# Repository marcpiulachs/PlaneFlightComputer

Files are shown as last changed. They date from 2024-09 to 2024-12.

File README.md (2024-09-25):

# Flight Computer

This project is a flight computer powered by an ESP32-C3 microcontroller, designed to control two motors and two servos. It integrates multiple sensors and supports a range of functionalities that make it suitable for small UAVs and drones. The system is designed to operate on a 300mAh LiPo battery, with built-in charging through USB-C.

## Features

- **ESP32-C3** microcontroller for reliable performance and wireless connectivity.
- **Motor Control:**
  - Motor 1: GPIO4
  - Motor 2: GPIO5
- **Servo Control:**
  - Servo 1: GPIO1
  - Servo 2: GPIO6
- **Sensors:**
  - **MAX17048G** (Fuel Gauge) on Address: `0x36` (00110110b)
  - **BMP388** (Barometric Pressure) on Address: `0x76` (1001100b)
  - **QMC5883L** (Magnetometer) on Address: `0x0d` (0001101b)
  - **ICM-42670-P** (6-axis IMU) on Address: `0x68` (1101000b)
- **LEDs:**
  - Internal LED: GPIO7
  - External LED: GPIO0
- **Battery:**
  - Recommended battery: **300mAh LiPo** for optimal performance
  - **USB-C charging** support for ease of use

## Recommended Hardware

- **Battery:** 300mAh LiPo
- **USB-C charger** (included)

## Pinout

| Component | GPIO Pin  | Description |
|---|---|---|
| Motor 1 | GPIO4 | Motor driver pin |
| Motor 2 | GPIO5 | Motor driver pin |
| Servo 1 | GPIO1 | Servo control pin |
| Servo 2 | GPIO6 | Servo control pin |
| Internal LED | GPIO7 | Status indicator |
| External LED | GPIO0 | Additional LED indicator |
| MAX17048G | I2C (0x36)| Fuel gauge sensor |
| BMP388 | I2C (0x76)| Barometric pressure sensor |
| QMC5883L | I2C (0x0d)| Magnetometer sensor |
| ICM-42670-P | I2C (0x68)| 6-axis IMU sensor |

## Power Management

The flight computer operates on a **300mAh LiPo battery**, which provides sufficient power for typical operations. For convenience, the board features **USB-C charging**, allowing you to charge the battery easily.

## Getting Started

To get started with the flight computer:

1. Connect the appropriate motors, servos, and sensors as listed in the pinout table.
2. Power the device using a 300mAh LiPo battery.
3. Use the onboard USB-C port to charge the battery when needed.

## License

This project is open source and available under the [MIT License](LICENSE).

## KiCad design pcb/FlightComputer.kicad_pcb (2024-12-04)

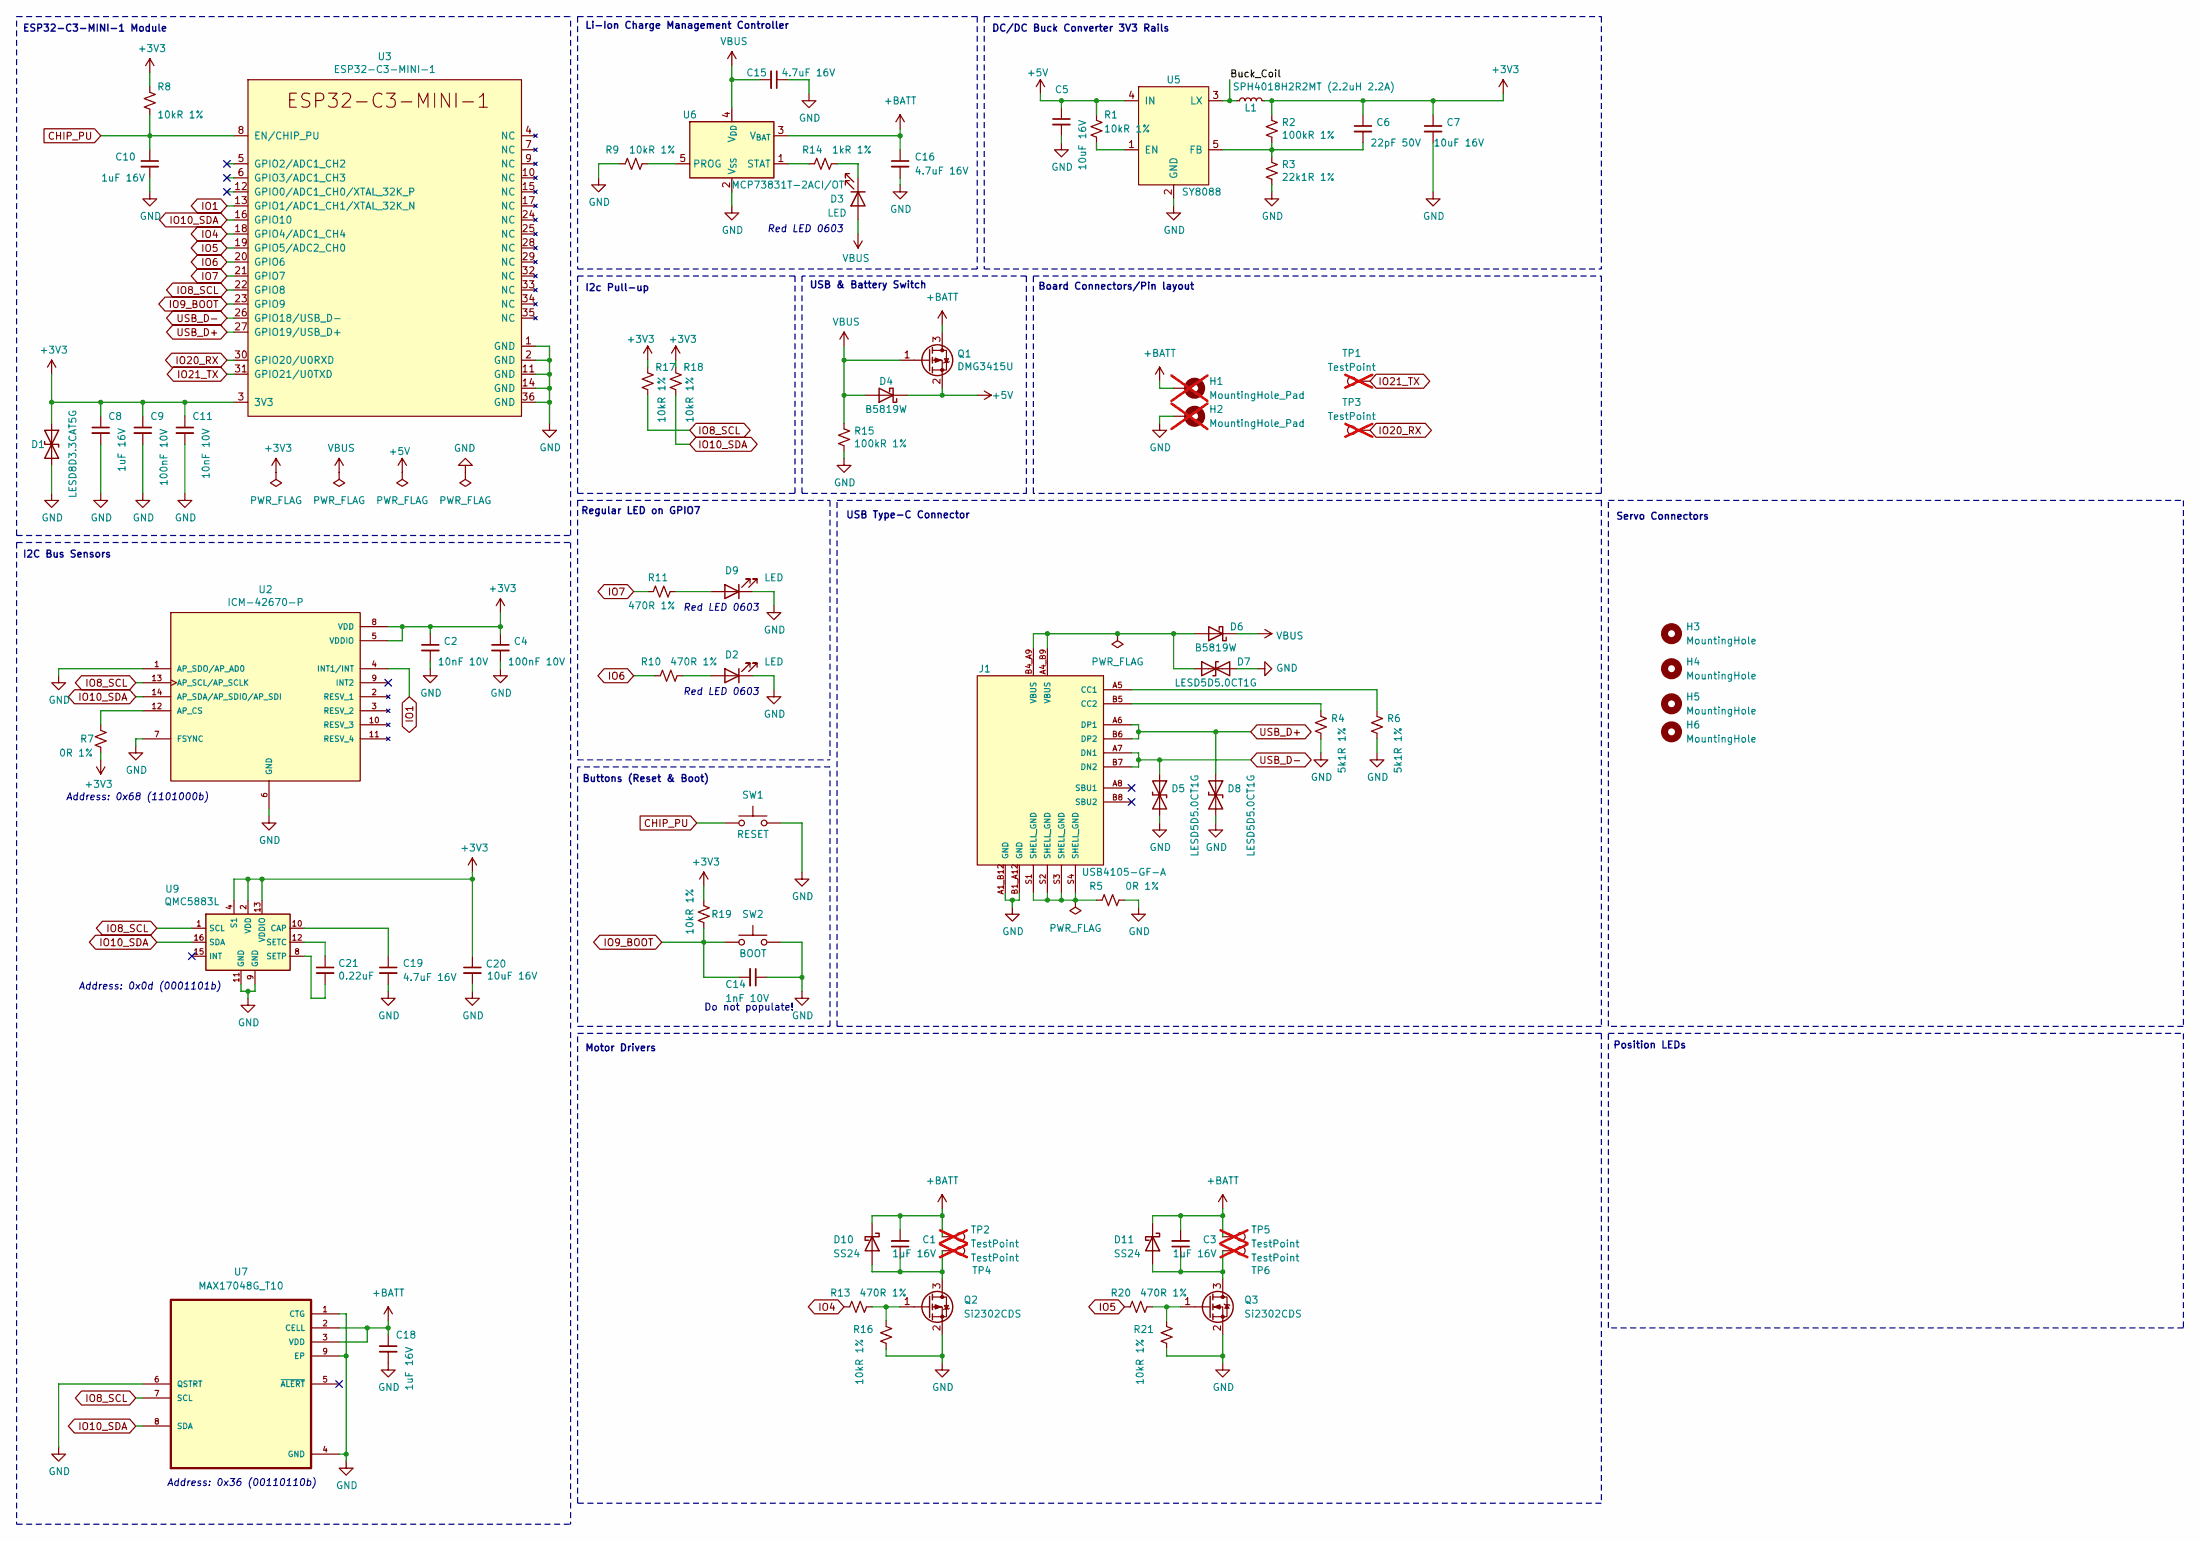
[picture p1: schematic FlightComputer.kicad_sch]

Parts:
C1, C3, C8, C10, C18: 1uF 16V; C_0402_1005Metric; LCSC C52923
C2, C11: 10nF 10V; C_0402_1005Metric; LCSC C15195
C4, C9: 100nF 10V; C_0402_1005Metric; LCSC C1525
C5, C7, C20: 10uF 16V; C_0805_2012Metric; LCSC C15850
C6: 22pF 50V; C_0603_1608Metric; LCSC C1653
C14: 1nF 10V; C_0402_1005Metric; LCSC C1523
C15, C16, C19: 4.7uF 16V; C_0603_1608Metric; LCSC C19666
C21: 0.22uF; C_0402_1005Metric; LCSC C16772
D1: LESD8D3.3CAT5G; D_SOD-882; LCSC C172409
D2, D3, D9: LED; LED_0603_1608Metric; LCSC C2286
D4, D6: B5819W; D_SOD-123; LCSC C8598
D5, D7, D8: LESD5D5.0CT1G; D_SOD-523; LCSC C383211
D10, D11: SS24; D_SOD-123; LCSC C5380709
H1, H2: MountingHole_Pad; TestPoint_Pad_D2.0mm; not fitted
H3, H4, H5, H6: MountingHole; MountingHole_2.2mm_M2_DIN965
J1: USB4105-GF-A; GCT_USB4105-GF-A; PARTREV A3; LCSC C165948
L1: SPH4018H2R2MT (2.2uH 2.2A); L_Bourns-SRN4018; LCSC C370436
Q1: DMG3415U; SOT-23; LCSC C96616
Q2, Q3: Si2302CDS; SOT-23; LCSC C10488
R1, R8, R9, R16, R17, R18, R19, R21: 10kR 1%; R_0402_1005Metric; LCSC C25744
R2, R15: 100kR 1%; R_0402_1005Metric; LCSC C25741
R3: 22k1R 1%; R_0402_1005Metric; LCSC C43473
R4, R6: 5k1R 1%; R_0402_1005Metric; LCSC C25905
R5, R7: 0R 1%; R_0402_1005Metric; LCSC C17168
R10, R11, R13, R20: 470R 1%; R_0402_1005Metric; LCSC C25117
R14: 1kR 1%; R_0402_1005Metric; LCSC C11702
SW1: RESET; SW_SPST_PTS810; LCSC C116501
SW2: BOOT; SW_SPST_PTS810; LCSC C116501
TP1, TP3: TestPoint; TestPoint_Pad_D1.0mm; not fitted
TP2, TP4, TP5, TP6: TestPoint; TestPoint_Pad_D2.0mm; not fitted
U2: ICM-42670-P; LGA-14_3x2.5mm_P0.5mm_LayoutBorder3x4y; PARTREV 1.0; LCSC C3288646
U3: ESP32-C3-MINI-1; LCSC C2838502
U5: SY8088; SOT-23-5; LCSC C479072
U6: MCP73831T-2ACI/OT; SOT-23-5; LCSC C424093
U7: MAX17048G_T10; TDFN-8-1EP_2x2mm_P0.5mm_EP0.8x1.2mm; LCSC C2682616
U9: QMC5883L; LGA-16_3x3mm_P0.5mm; LCSC C976032

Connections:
+3V3: C2.1, C4.1, C6.1, C7.1, C8.1, C9.1, C11.1, C20.1, D1.1 (A1), L1.2, R2.1, R7.2, R8.1, R17.1, R18.1, R19.1, U2.5 (VDDIO), U2.8 (VDD), U3.3 (3V3), U9.2 (VDD), U9.4 (S1), U9.13 (VDDIO)
+5V: C5.1, D4.1 (K), Q1.2 (S), R1.1, U5.4 (IN)
+BATT: C1.2, C3.2, C16.1, C18.1, D10.1 (K), D11.1 (K), H1.1, Q1.3 (D), TP2.1, TP5.1, U6.3 (V_{BAT}), U7.2 (CELL), U7.3 (VDD)
/Buck_Coil: L1.1, U5.3 (LX)
CHIP_PU: C10.1, R8.2, SW1.1, U3.8 (EN/CHIP_PU)
GND: C2.2, C4.2, C5.2, C7.2, C8.2, C9.2, C10.2, C11.2, C14.1, C15.1, C16.2, C18.2, C19.2, C20.2, D1.2 (A2), D2.1 (K), D5.2 (A2), D7.2 (A2), D8.2 (A2), D9.1 (K), H2.1, J1.A1_B12 (GND), J1.B1_A12 (GND), Q2.2 (S), Q3.2 (S), R3.2, R4.2, R5.2, R6.2, R9.1, R15.2, R16.2, R21.2, SW1.2, SW2.2, U2.1 (AP_SDO/AP_AD0), U2.6 (GND), U2.7 (FSYNC), U3.1 (GND), U3.2 (GND), U3.11 (GND), U3.14 (GND), U3.36 (GND), U5.2 (GND), U6.2 (V_{SS}), U7.1 (CTG), U7.4 (GND), U7.6 (QSTRT), U7.9 (EP), U9.9 (GND), U9.11 (GND)
IO4: R13.1, U3.18 (GPIO4/ADC1_CH4)
IO5: R20.1, U3.19 (GPIO5/ADC2_CH0)
IO6: R10.1, U3.20 (GPIO6)
IO7: R11.1, U3.21 (GPIO7)
IO8_SCL: R17.2, U2.13 (AP_SCL/AP_SCLK), U3.22 (GPIO8), U7.7 (SCL), U9.1 (SCL)
IO9_BOOT: C14.2, R19.2, SW2.1, U3.23 (GPIO9)
IO10_SDA: R18.2, U2.14 (AP_SDA/AP_SDIO/AP_SDI), U3.16 (GPIO10), U7.8 (SDA), U9.16 (SDA)
IO13: U2.4 (INT1/INT), U3.13 (GPIO1/ADC1_CH1/XTAL_32K_N)
IO20_RX: TP3.1, U3.30 (GPIO20/U0RXD)
IO21_TX: TP1.1, U3.31 (GPIO21/U0TXD)
unnamed: D2.2 (A), R10.2
unnamed: D3.1 (K), R14.2
unnamed: D6.2 (A), D7.1 (A1), J1.A4_B9 (VBUS), J1.B4_A9 (VBUS)
unnamed: D9.2 (A), R11.2
unnamed: C1.1, D10.2 (A), Q2.3 (D), TP4.1
unnamed: C3.1, D11.2 (A), Q3.3 (D), TP6.1
unnamed: J1.A5 (CC1), R6.1
unnamed: J1.B5 (CC2), R4.1
unnamed: J1.S1 (SHELL_GND), J1.S2 (SHELL_GND), J1.S3 (SHELL_GND), J1.S4 (SHELL_GND), R5.1
unnamed: Q2.1 (G), R13.2, R16.1
unnamed: Q3.1 (G), R20.2, R21.1
unnamed: R7.1, U2.12 (AP_CS)
unnamed: R1.2, U5.1 (EN)
unnamed: C6.2, R2.2, R3.1, U5.5 (FB)
unnamed: R9.2, U6.5 (PROG)
unnamed: R14.1, U6.1 (STAT)
unnamed: C19.1, U9.10 (CAP)
unnamed: C21.1, U9.12 (SETC)
unnamed: C21.2, U9.8 (SETP)
USB_D+: D8.1 (A1), J1.A6 (DP1), J1.B6 (DP2), U3.27 (GPIO19/USB_D+)
USB_D-: D5.1 (A1), J1.A7 (DN1), J1.B7 (DN2), U3.26 (GPIO18/USB_D-)
VBUS: C15.2, D3.2 (A), D4.2 (A), D6.1 (K), Q1.1 (G), R15.1, U6.4 (V_{DD})

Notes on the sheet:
USB Type-C Connector
Do not populate!
Buttons (Reset & Boot)
Servo Connectors
Red LED 0603
Motor Drivers
I2c Pull-up
DC/DC Buck Converter 3V3 Rails
USB & Battery Switch
Board Connectors/Pin layout
Address: 0x36 (00110110b)
Address: 0x0d (0001101b)
Regular LED on GPIO7
Position LEDs
Address: 0x68 (1101000b)
ESP32-C3-MINI-1 Module
Li-Ion Charge Management Controller
I2C Bus Sensors

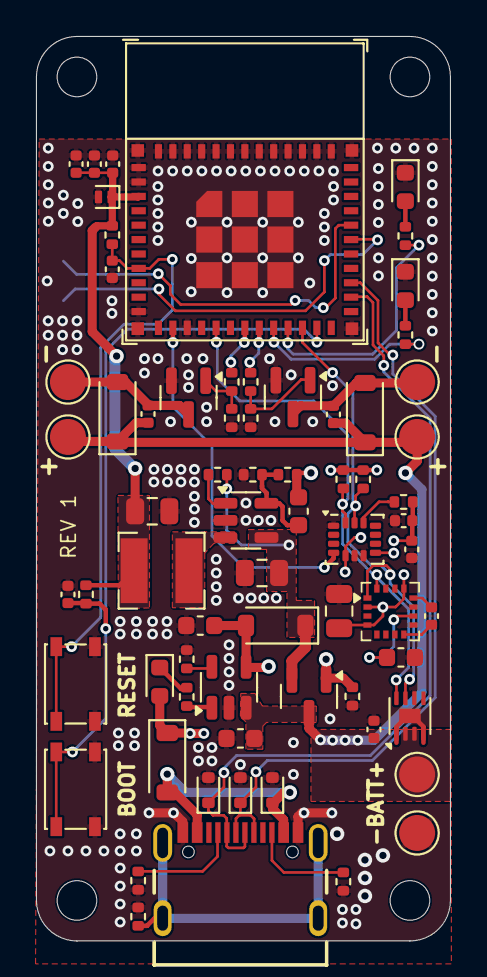
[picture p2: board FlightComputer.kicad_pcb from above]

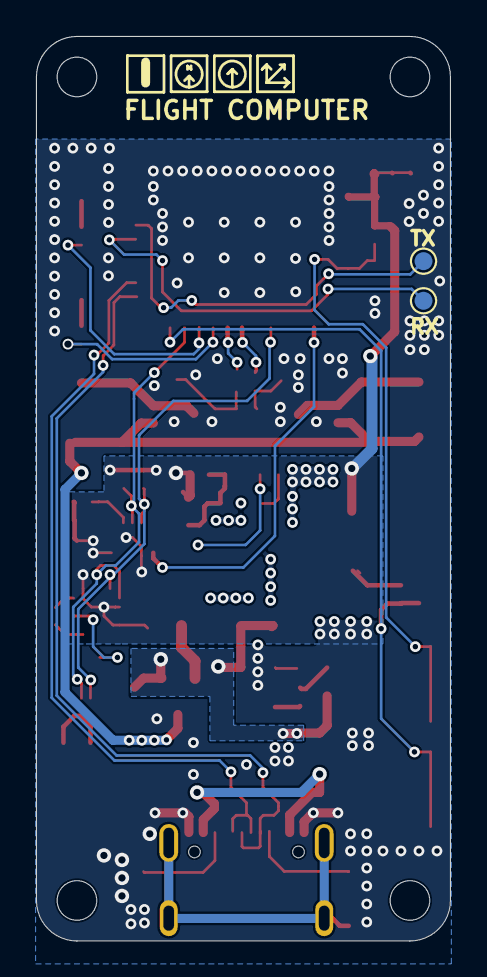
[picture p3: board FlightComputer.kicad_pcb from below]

Board: 2 copper layers, 23.0 x 50.2 mm, 74 parts (2 on the bottom side), 38 nets.

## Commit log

2024-09-06 Remove production files
    [esp-rust-board-B_Cu.gbr, esp-rust-board-B_Mask.gbr, esp-rust-board-B_Paste.gbr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]
2024-09-06 Port kicad 8.0
    [esp-rust-board.kicad_pcb, esp-rust-board.kicad_sch]
2024-09-06 Clean up, update symbols and footprints, port to Kicad 8.0
    [esp-rust-board.kicad_pcb, esp-rust-board.kicad_sch]
2024-09-06 Solve remaining errors and warnings
    [esp-rust-board.kicad_pcb, esp-rust-board.kicad_sch]
2024-09-06 Update package
    [esp-rust-board.kicad_pcb, esp-rust-board.kicad_sch]
2024-09-06 Clean up not used footprints
    [esp-rust-board.kicad_pcb]
2024-09-06 Add new components
    [esp-rust-board.kicad_pcb, esp-rust-board.kicad_sch]
2024-09-10 Work in progress
    [esp-rust-board.kicad_pcb, esp-rust-board.kicad_sch]
2024-09-14 Add magnamometer and barometer and rearrange items
    [esp-rust-board.kicad_pcb, esp-rust-board.kicad_sch]
2024-09-18 Reorganize PCB, remove piezo, temperature sensor and expansion connections
    [esp-rust-board.kicad_pcb, esp-rust-board.kicad_sch]
2024-09-19 Add missing components
    [esp-rust-board.kicad_pcb, esp-rust-board.kicad_sch]
2024-09-19 Place components on PCB
    [esp-rust-board.kicad_pcb, esp-rust-board.kicad_sch]
2024-09-19 Add missing LCSC parts
    [esp-rust-board.kicad_sch]
2024-09-19 Minor corrections
    [esp-rust-board.kicad_pcb]
2024-09-20 Design completed
    [esp-rust-board.kicad_pcb, esp-rust-board.kicad_sch]
2024-09-20 Remove unused rust board
    [esp-rust-board.kicad_pcb, esp-rust-board.kicad_sch]
2024-09-20 Rename Kicad project, rearrange folder structure
    [FlightComputer.kicad_pcb, FlightComputer.kicad_sch]
2024-09-20 Rearrange some vias, minor changes
    [FlightComputer.kicad_pcb, FlightComputer.kicad_sch]
2024-09-25 BMP280 > BMP388
    [FlightComputer.kicad_pcb, FlightComputer.kicad_sch]
2024-09-25 add a few vias, move traces
    [FlightComputer.kicad_pcb]
2024-09-25 Change BMP388 pin to input to reduce warnings
2024-09-25 Correct switch symbol to reduce warnings
    [FlightComputer.kicad_pcb, FlightComputer.kicad_sch]
2024-09-27 Move resistors
    [FlightComputer.kicad_pcb]
2024-09-27 Rotate servos pinouts
    [FlightComputer.kicad_pcb, FlightComputer.kicad_sch]
2024-11-28 Remove barometer
    [FlightComputer.kicad_pcb, FlightComputer.kicad_sch]
2024-12-03 Reduce board size
    [FlightComputer.kicad_pcb, FlightComputer.kicad_sch]
2024-12-03 change Si2319CDS to Si2302CDS
    [FlightComputer.kicad_pcb, FlightComputer.kicad_sch]
2024-12-03 Move battery pads to front
    [FlightComputer.kicad_pcb]
2024-12-03 Change label sizes
    [FlightComputer.kicad_pcb]
2024-12-03 Connect IO0 to IMU interrupt
    [FlightComputer.kicad_pcb, FlightComputer.kicad_sch]
2024-12-04 Hide labels
    [FlightComputer.kicad_pcb]
2024-12-04 Add GND vias, clean up schematic
    [FlightComputer.kicad_pcb, FlightComputer.kicad_sch]
2024-12-04 clean up zones
    [FlightComputer.kicad_pcb]
